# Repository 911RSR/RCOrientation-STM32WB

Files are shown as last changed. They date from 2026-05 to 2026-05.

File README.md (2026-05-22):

# RCOrientation-STM32WB

STM32WB55 firmware for an Android-controlled roll / pitch / yaw servo receiver.

This project runs on a WeActStudio STM32WB55 CoreBoard and pairs with the companion Android app, [RCOrientation-Android](https://github.com/911RSR/RCOrientation-Android). The Android phone sends orientation commands over BLE; the STM32WB drives RC servos and reports actuator positions back.

## Current status

Working bench prototype:

- advertises as `RCOrient`
- requires BLE pairing, bonding, and encrypted access to the control characteristics
- receives roll / pitch / yaw commands from the Android app
- configures four servo PWM outputs on `PA0..PA3 / TIM2_CH1..CH4`
- reports servo positions back to the app

Servo mixer with direct forwarding:

- roll drives `servo_us[0]`
- pitch drives `servo_us[1]`
- yaw drives `servo_us[2]`
- `servo_us[3]` stays neutral
- approximately `-45 deg .. +45 deg` maps to `1000 us .. 2000 us`

This mixer is mainly for bench testing, although it could teoretically be used for short-range RC plane control; 
A later mixer will map roll / pitch / yaw / gyro demands into the real actuator geometry.

## Hardware

Tested with:

- WeActStudio STM32WB55 CoreBoard
- STM32WB55CGU6
- ST BLE wireless stack already flashed on CPU2

Current bench wiring:

| Function | STM32 pin | Peripheral |
| --- | --- | --- |
| Servo 0 PWM | `PA0` | `TIM2_CH1` |
| Servo 1 PWM | `PA1` | `TIM2_CH2` |
| Servo 2 PWM | `PA2` | `TIM2_CH3` |
| Servo 3 PWM | `PA3` | `TIM2_CH4` |

Servo PWM is currently configured for 300 Hz with 1 us resolution during latency testing.

The STM32WB board and servos may share the same battery source if the board regulator input range allows it and the servo voltage is appropriate. The supply must tolerate servo current spikes without excessive voltage droop or ground bounce. Standard servos generally need a regulated 5–6 V rail; HV servos may allow 2S LiPo directly. Always verify voltage limits for both the STM32 board input regulator and the servos.

## BLE protocol

Service UUID: `7B5D0000-6A2E-4D6B-9E6F-8D2B7C5A1100`

| Characteristic | Direction | Properties | Size |
| --- | --- | --- | --- |
| `0x0001` Orientation command | phone -> STM32WB | encrypted write / write without response | 8 bytes |
| `0x0002` Servo feedback | STM32WB -> phone | encrypted read / notify | 10 bytes |

Orientation command payload:

```c
int16_t roll_cdeg;
int16_t pitch_cdeg;
int16_t yaw_cdeg;
uint16_t sequence;
```

Servo feedback payload:

```c
int16_t servo_us[4];
uint16_t sequence;
```

## Build and flash

1. Open `RCOrientation-STM32WB.ioc` in STM32CubeMX or STM32CubeIDE.
2. Let STM32CubeIDE/CubeMX generate the local Eclipse project metadata on your own PC.
3. Build the project in STM32CubeIDE.
4. Flash it to the WeAct STM32WB55 board using your normal ST-LINK / STM32CubeIDE workflow.
5. Pair from the Android app before expecting control traffic to flow.

The `.project`, `.cproject`, `.mxproject`, `.settings/`, and `*.launch` files are intentionally not tracked because STM32CubeIDE fills them with machine-local paths.

## CubeMX regeneration notes

The `.ioc` file is intended to be the source of truth for generated hardware setup. It currently describes:

- `PA0..PA3 / TIM2_CH1..CH4` as PWM outputs for `servo_us[0..3]`
- the `RCOrient` BLE identity
- the orientation-service naming and packet sizes
- bonding enabled with no-input/no-output capability

Application logic should stay outside generated files where practical. Project-specific code currently lives in:

- `Core/Inc/orientation_protocol.h`
- `Core/Inc/orientation_app.h` and `Core/Src/orientation_app.c`
- `Core/Inc/mixer.h` and `Core/Src/mixer.c`
- `Core/Inc/servo_output.h` and `Core/Src/servo_output.c`

BLE service and generated application hooks currently live in:

- `STM32_WPAN/App/custom_stm.*`
- `STM32_WPAN/App/custom_app.*`

Current CubeMX versions used during development regenerate duplicate BLE stubs for the read+notify feedback characteristic. Until ST fixes that generator bug, run this after code generation:

```powershell
.\tools\fix-cubemx-ble-duplicates.ps1
```

## Security note

The present configuration requires a bonded encrypted BLE link. It uses a simple no-input/no-output pairing mode, so it does not provide man-in-the-middle protection during the very first pairing ceremony.

## Related project

- Android app: [RCOrientation-Android](https://github.com/911RSR/RCOrientation-Android)

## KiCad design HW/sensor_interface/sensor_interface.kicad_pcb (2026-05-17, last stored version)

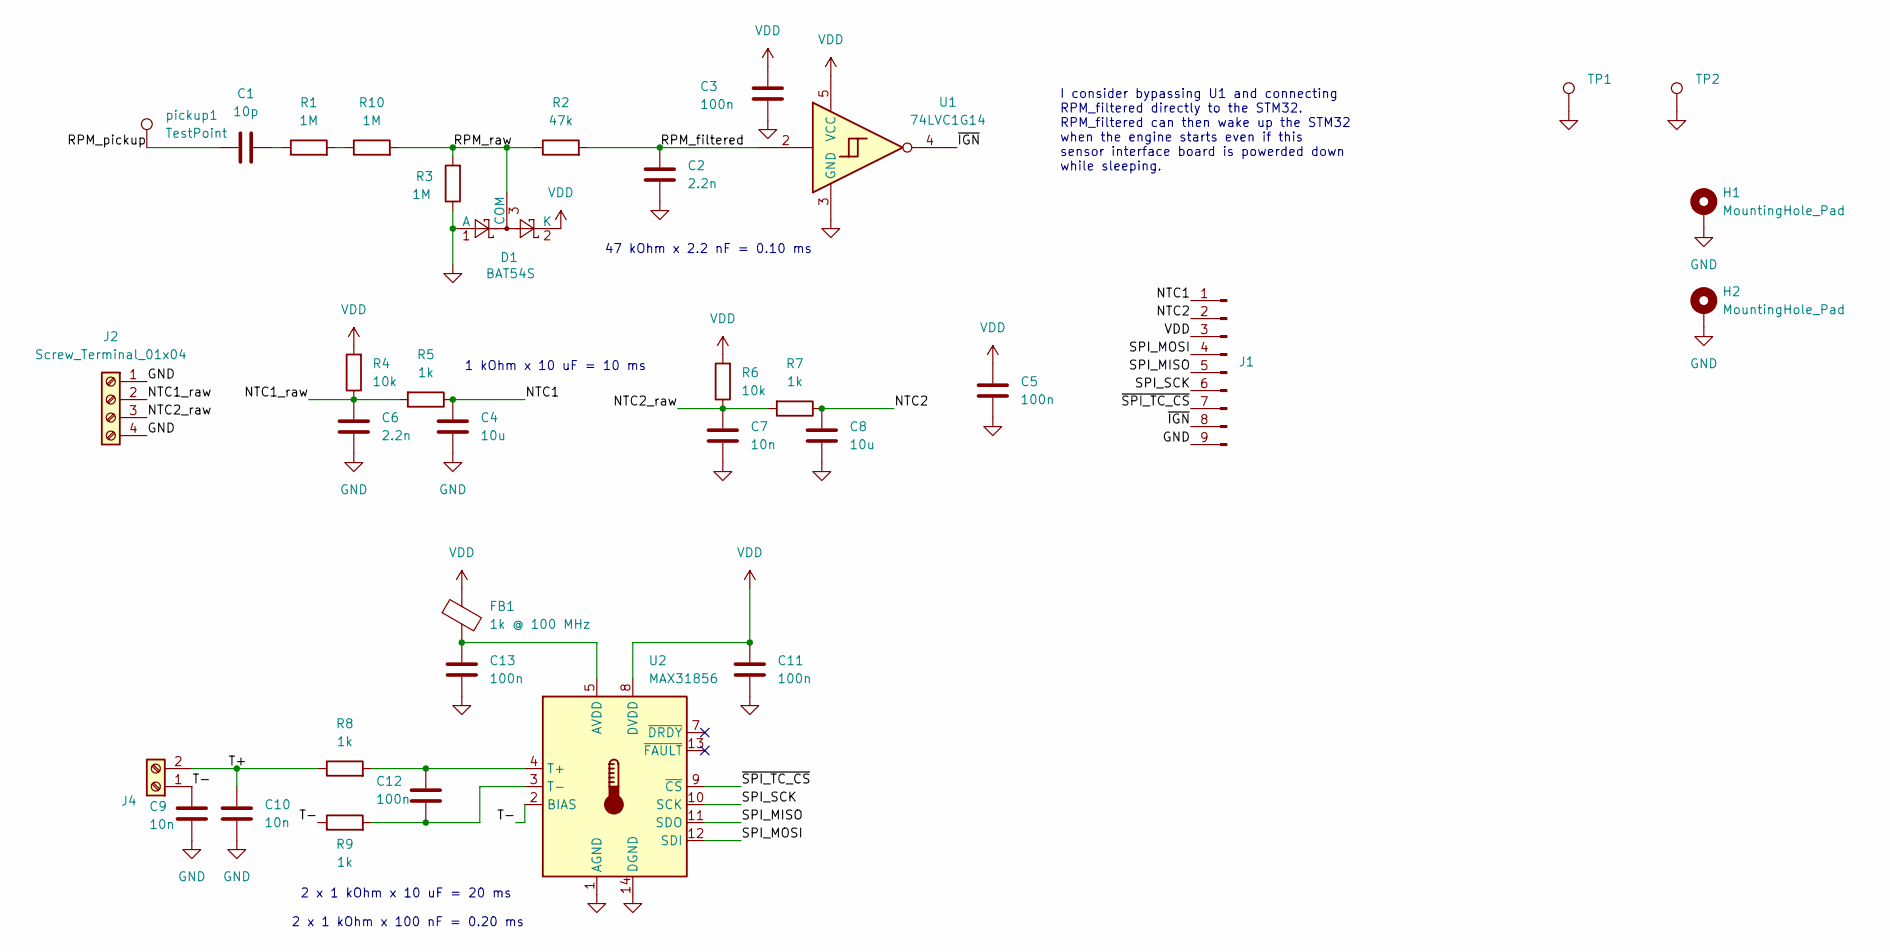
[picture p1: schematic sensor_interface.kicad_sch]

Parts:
C1: 10p; C_0805_2012Metric; MPN CC0805JRNPOCBN100
C2: 2.2n; C_0805_2012Metric; MPN C0805C222KAGECAUTO
C3, C5, C11, C12, C13: 100n; C_0805_2012Metric
C4, C8: 10u; C_0805_2012Metric
C6: 2.2n; C_0805_2012Metric
C7, C9, C10: 10n; C_0805_2012Metric
D1: BAT54S; SOT-23; MPN BAT54S
FB1: 1k @ 100 MHz; R_0805_2012Metric
H1, H2: MountingHole_Pad; MountingHole_3.2mm_M3_Pad_Via
J1: Berg; PinHeader_1x09_P2.54mm_Vertical
J2: Screw_Terminal_01x04; TerminalBlock_Phoenix_MPT-0,5-4-2.54_1x04_P2.54mm_Horizontal
J4: Screw_Terminal; TerminalBlock_Phoenix_MPT-0,5-2-2.54_1x02_P2.54mm_Horizontal
R1: 1M; R_0805_2012Metric; MPN CRCW08051M00FKEA
R2: 47k; R_0805_2012Metric
R3, R10: 1M; R_0805_2012Metric
R4, R6: 10k; R_0805_2012Metric
R5, R7, R8, R9: 1k; R_0805_2012Metric
TP1, TP2: TestPoint; TestPoint_THTPad_4.0x4.0mm_Drill2.0mm
U1: 74LVC1G14; SOT-23-5_HandSoldering
U2: MAX31856; TSSOP-14_4.4x5mm_P0.65mm; MPN MAX31856MUD+T
pickup1: TestPoint; TestPoint_THTPad_D4.0mm_Drill2.0mm

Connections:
/NTC1: C4.2, J1.1, R5.1
/NTC1_raw: C6.2, J2.2, R4.1, R5.2
/NTC2: C8.2, J1.2, R7.1
/NTC2_raw: C7.2, J2.3, R6.1, R7.2
/RPM_filtered: C2.2, R2.2, U1.2
/RPM_pickup: C1.1, pickup1.1 (1_1)
/RPM_raw: D1.3 (COM), R2.1, R3.2, R10.2
/SPI_MISO: J1.5, U2.11 (SDO)
/SPI_MOSI: J1.4, U2.12 (SDI)
/SPI_SCK: J1.6, U2.10 (SCK)
/SPI_TC_CS: J1.7, U2.9 (~CS)
/T+: C10.2, J4.2, R8.1
/T-: C9.2, J4.1, R9.1, U2.2 (BIAS)
/~IGN: J1.8, U1.4
GND: C2.1, C3.1, C4.1, C5.1, C6.1, C7.1, C8.1, C9.1, C10.1, C11.1, C13.1, D1.1 (A), H1.1 (1_1), H2.1 (1_1), J1.9, J2.1, J2.4, R3.1, TP1.1 (1_1), TP2.1 (1_1), U1.3 (GND), U2.1 (AGND), U2.14 (DGND)
unnamed: C1.2, R1.1
unnamed: R1.2, R10.1
unnamed: C13.2, FB1.2, U2.5 (AVDD)
unnamed: C12.2, R8.2, U2.4 (T+)
unnamed: C12.1, R9.2, U2.3 (T-)
VDD: C3.2, C5.2, C11.2, D1.2 (K), FB1.1, J1.3, R4.2, R6.2, U1.5 (VCC), U2.8 (DVDD)

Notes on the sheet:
2 x 1 kOhm x 10 uF = 20 ms
I consider bypassing U1 and connecting RPM_filtered directly to the STM32. RPM_filtered can then wake up the STM32 when the engine starts even if this sensor interface board is powerded down while sleeping.
47 kOhm x 2.2 nF = 0.10 ms
2 x 1 kOhm x 100 nF = 0.20 ms
1 kOhm x 10 uF = 10 ms

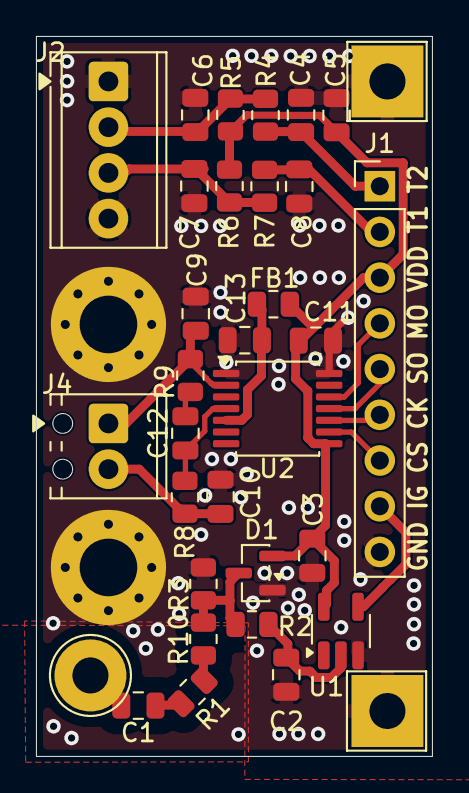
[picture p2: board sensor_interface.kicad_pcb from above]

Board: 2 copper layers, 22.0 x 40.0 mm, 35 parts (0 on the bottom side), 21 nets.

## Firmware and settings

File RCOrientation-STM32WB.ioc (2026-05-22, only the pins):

Mcu.UserName=STM32WB55CGUx
PA0.GPIO_Label=SERVO_PWM0
PA0.Signal=S_TIM2_CH1
PA1.GPIO_Label=SERVO_PWM1
PA1.Signal=S_TIM2_CH2
PA11.Signal=USB_DM
PA12.Signal=USB_DP
PA13.Signal=SYS_JTMS-SWDIO
PA14.Signal=SYS_JTCK-SWCLK
PA2.GPIO_Label=SERVO_PWM2
PA2.Signal=S_TIM2_CH3
PA3.GPIO_Label=SERVO_PWM3
PA3.Signal=S_TIM2_CH4
PB3.Signal=SPI1_SCK
PB4.Signal=SPI1_MISO
PB5.Signal=SPI1_MOSI
PB6.Signal=USART1_TX
PB7.Signal=USART1_RX
PB8.GPIO_Label=MPU_SCL
PB8.Signal=I2C1_SCL
PB9.GPIO_Label=MPU_SDA
PB9.Signal=I2C1_SDA
PC14-OSC32_IN.Signal=RCC_OSC32_IN
PC15-OSC32_OUT.Signal=RCC_OSC32_OUT
PE4.GPIO_Label=LED
PE4.Signal=GPIO_Output

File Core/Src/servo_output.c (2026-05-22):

#include "servo_output.h"

#include "main.h"
#include "tim.h"

static uint16_t ServoUs[SERVO_COUNT] = {
    SERVO_NEUTRAL_US,
    SERVO_NEUTRAL_US,
    SERVO_NEUTRAL_US,
    SERVO_NEUTRAL_US,
};

static const uint32_t ServoTimerChannels[SERVO_COUNT] = {
    TIM_CHANNEL_1,
    TIM_CHANNEL_2,
    TIM_CHANNEL_3,
    TIM_CHANNEL_4,
};

static int16_t clamp_servo_us(int16_t pulse_us)
{
  if (pulse_us < SERVO_MIN_US) return SERVO_MIN_US;
  if (pulse_us > SERVO_MAX_US) return SERVO_MAX_US;
  return pulse_us;
}

void ServoOutput_Init(void)
{
  /* Only PA0..PA2 are populated on the bench today; PA3 is configured but left idle. */
  for (uint8_t servo_index = 0; servo_index < 3U; servo_index++)
  {
    if (HAL_TIM_PWM_Start(&htim2, ServoTimerChannels[servo_index]) != HAL_OK)
    {
      Error_Handler();
    }
    __HAL_TIM_SET_COMPARE(&htim2, ServoTimerChannels[servo_index], (uint16_t)ServoUs[servo_index]);
  }
}

void ServoOutput_SetUs(uint8_t servo_index, uint16_t pulse_us)
{
  if (servo_index >= SERVO_COUNT)
  {
    return;
  }

  ServoUs[servo_index] = clamp_servo_us(pulse_us);

  /* Servo 3 / PA3 is reserved in the model but not physically populated yet. */
  if (servo_index < 3U)
  {
    __HAL_TIM_SET_COMPARE(&htim2, ServoTimerChannels[servo_index], ServoUs[servo_index]);
  }
}

void ServoOutput_SetAllUs(const uint16_t pulse_us[SERVO_COUNT])
{
  if (pulse_us == 0)
  {
    return;
  }

  for (uint8_t servo_index = 0; servo_index < SERVO_COUNT; servo_index++)
  {
    ServoOutput_SetUs(servo_index, pulse_us[servo_index]);
  }
}

const uint16_t *ServoOutput_GetAllUs(void)
{
  return ServoUs;
}

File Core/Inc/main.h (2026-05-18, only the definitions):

#define RPM /* delete if you do not use an ignition probe */
#define ADC_range 4095.0
#define MPU_SCL_Pin GPIO_PIN_8
#define MPU_SCL_GPIO_Port GPIOB
#define MPU_SDA_Pin GPIO_PIN_9
#define MPU_SDA_GPIO_Port GPIOB
#define SERVO_PWM0_Pin GPIO_PIN_0
#define SERVO_PWM0_GPIO_Port GPIOA
#define SERVO_PWM1_Pin GPIO_PIN_1
#define SERVO_PWM1_GPIO_Port GPIOA
#define SERVO_PWM2_Pin GPIO_PIN_2
#define SERVO_PWM2_GPIO_Port GPIOA
#define SERVO_PWM3_Pin GPIO_PIN_3
#define SERVO_PWM3_GPIO_Port GPIOA
#define LED_Pin GPIO_PIN_4
#define LED_GPIO_Port GPIOE

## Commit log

2026-05-17 Remove inherited RaceTemp leftovers
    [sensor_interface.kicad_pcb, sensor_interface.kicad_sch]
2026-05-18 Align CubeMX model and add servo mixer layers
2026-05-18 Track STM32 project files for fresh clones
2026-05-18 Revise servo mixer description in README
    Updated the description of the servo mixer for clarity.
2026-05-19 Remove local IDE metadata from STM32 repo
2026-05-22 Changd us type to uint16_t. Changed servo mixer interface to float radians
2026-05-22 Update README with battery and voltage information
    Added information about battery source and voltage requirements for STM32WB board and servos.

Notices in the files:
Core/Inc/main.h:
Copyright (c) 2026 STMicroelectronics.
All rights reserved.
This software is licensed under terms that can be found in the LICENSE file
